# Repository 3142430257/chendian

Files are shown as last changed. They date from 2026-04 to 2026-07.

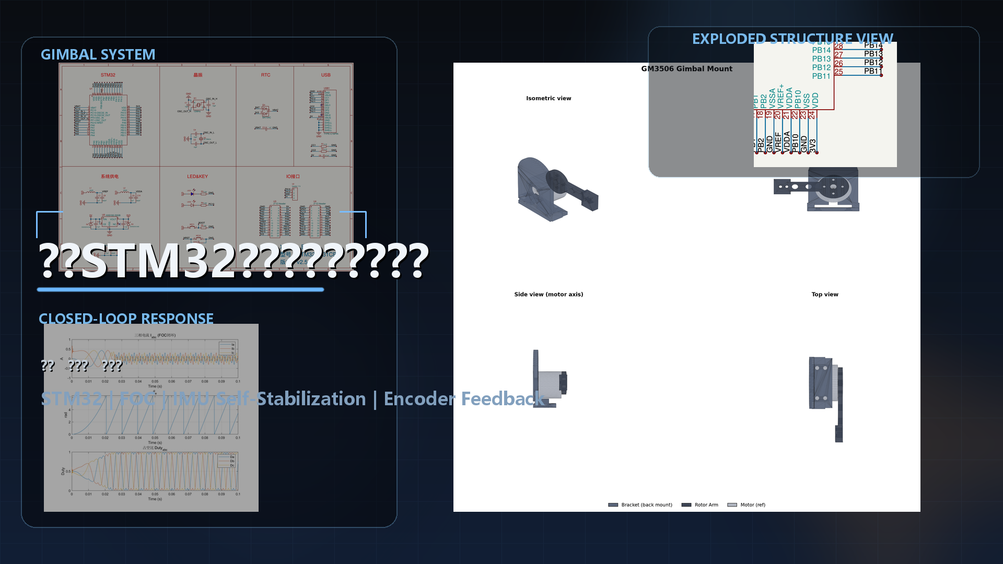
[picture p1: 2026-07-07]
docs/media/video_intro_cover_gimbal_stm32.png

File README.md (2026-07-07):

# STM32G431 FOC 单轴云台自稳系统

基于 **STM32G431CBT6 + GM3506 无刷云台电机** 的单轴 FOC 姿态自稳系统。项目覆盖下位机固件、Qt 图形上位机、Simulink 电流环模型、机械结构和竞赛文档。

全国大学生嵌入式芯片与系统设计竞赛 2026 · 意法半导体赛道 · 选题四：工业 4.0 / 电机控制 / 机器人

## 功能概览

| 功能 | 命令序列 | 说明 |
|---|---|---|
| 电角度校准 | `a` | 旋转式 ALIGN，建立可靠 dq 坐标 |
| 闭环速度控制 | `a -> e -> S40 -> S-40 -> S0 -> d` | 支持正反转和停机 |
| 单轴云台自稳 | `a -> e -> H -> G` | 底座倾斜时，负载臂保持相对水平 |
| 遥测与诊断 | Qt 上位机连接串口 | 实时显示位置、Iq、IMU pitch 和状态 |

## 系统架构

```text
MPU6050 IMU
    |
    v
位置目标 -> ISR 级位置 PID -> IqRef -> Simulink 电流 PI -> SVPWM -> GM3506
              ^                                             |
              |                                             v
        AS5048A SPI 编码器 <----------------------------- 转子位置
```

- **电流环**：Simulink 生成 PI 控制器，20 kHz PWM/ADC 同步中断执行。
- **位置环**：ISR 级 PID，使用编码器角度反馈，支持非线性 KP 和积分补偿。
- **校准流程**：开环旋转采样 + 电角度修正 + Iq 脉冲方向验证。
- **自稳模式**：MPU6050 pitch 映射为位置目标，电机反向补偿底座倾斜。
- **通信接口**：USART3，115200 8N1，支持单字符/行命令和 `T,...` CSV 遥测。

## 硬件组成

| 模块 | 型号/说明 |
|---|---|
| MCU | STM32G431CBT6，Cortex-M4，170 MHz |
| 电机 | GM3506 无刷云台电机，11 极对 |
| 驱动板 | ATK-PD6010B |
| 编码器 | AS5048A，14 bit SPI 磁编码器 |
| IMU | MPU6050，I2C |
| 电源 | 12 V DC |
| 串口 | USART3，PB10 TX，PB11 RX，115200 8N1 |

## 仓库结构

```text
firmware/
  STM32G431CBT6_motor/       当前主固件工程，CMake 构建
    App/                     FOC 接口、状态机、编码器、IMU、遥测
    Core/                    CubeMX 生成的 HAL 外设代码
  cubemx_reference/          早期 CubeMX 参考工程

host/
  qt_host/                   PySide6 图形上位机

models/
  foc_controller.slx         Simulink 电流环模型
  foc_sim.slx                闭环仿真模型
  foc_params.m               电机和 PI 参数
  foc_controller_ert_rtw/    Simulink Coder 生成代码与报告

hardware/
  gimbal_mount/              3D 打印支架 STL 与渲染图
  schematics_and_package/    原理图、封装、器件资料
  controller_board/          主控/驱动板参考资料

docs/
  report/                    竞赛报告与技术文档
  media/                     README/报告用图片
  references/                外部参考资料
```

说明：本地调试脚本目录 `tools/` 不上传 GitHub，已在 `.gitignore` 中忽略。

## 编译与烧录

依赖：

- STM32CubeCLT，包含 `arm-none-eabi-gcc`、CMake/Ninja 和 STM32CubeProgrammer
- STM32G431CBT6 目标板，SWD 下载接口

编译：

```powershell
cd firmware\STM32G431CBT6_motor
cmake --preset Debug
cmake --build --preset Debug
```

使用 STM32CubeProgrammer CLI 烧录：

```powershell
& 'D:\STM32CubeCLT_1.21.0\STM32CubeProgrammer\bin\STM32_Programmer_CLI.exe' `
  -c port=SWD mode=UR reset=HWrst `
  -w 'build\Debug\STM32G431CBT6_motor.elf' `
  -v -rst
```

如果 CMake 在中文路径下异常，建议把仓库复制到纯英文路径后再编译。

## Qt 上位机

依赖：

- Python 3.10+
- PySide6
- pyqtgraph
- pyserial
- numpy

启动：

```powershell
cd host\qt_host
pip install -r requirements.txt
python main.py
```

连接方式：

- USB 转 TTL 接 MCU `USART3 @ 115200`
- MCU `PB10` 为 TX，接 USB 转 TTL RX
- MCU `PB11` 为 RX，接 USB 转 TTL TX
- GND 必须共地
- 上电后等待状态进入 `ST=READY`，再执行使能或自稳流程

## 串口命令

| 命令 | 功能 |
|---|---|
| `a` | 旋转式电角度校准，ALIGN |
| `e` | 进入 RUN 使能状态 |
| `d` | 停机 |
| `H` | 将当前位置设为 Home 零点 |
| `G` | 启动 IMU 自稳模式 |
| `S<dps>` | 速度模式，例如 `S40` 表示 40 deg/s |
| `I<A>` | 直接力矩注入，例如 `I0.15` |
| `O` | 开环旋转测试 |
| `X` | 停止开环测试 |
| `F<deg>` | 手动微调电角度偏移 |

典型流程：

```text
a -> e -> H -> G
```

## 关键参数

| 参数 | 值 | 说明 |
|---|---|---|
| 电流环频率 | 20 kHz | PWM/ADC 同步 ISR |
| 电流环带宽 | 200 Hz | Simulink PI |
| 位置环更新 | 约 1 kHz | 编码器反馈 |
| 遥测频率 | 100 Hz | UART CSV 帧 |
| ISR_KP_NEAR | 0.015 A/deg | 小误差位置增益 |
| ISR_KP_FAR | 0.030 A/deg | 大误差位置增益 |
| ISR_KD | 0.010 A/(deg/s) | 阻尼项 |
| ISR_KI | 0.0005 A/(deg*s) | 重力静差积分补偿 |
| 速度保护 | 400 deg/s | ISR 级切断力矩 |

## 开发说明

- 主固件入口：`firmware/STM32G431CBT6_motor/`
- Qt 上位机入口：`host/qt_host/main.py`
- 电流环模型：`models/foc_controller.slx`
- 竞赛报告草稿：`docs/report/竞赛作品报告_填报稿.md`
- 本地视频、压缩包和调试脚本不纳入 GitHub

## 许可证

MIT License

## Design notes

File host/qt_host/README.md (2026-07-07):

# FOC 云台 Qt 上位机

深色工业风桌面控制台，对接固件 **USART3 @ 115200** CSV 遥测与单字符/行命令协议。

## 功能

- 串口连接、实时解析 `T,...` 遥测与 `[CMD]` 回显
- 实时曲线：位置 / Iq / IMU Pitch（约 60 s 滚动窗口）
- 一键流程：**校准 (a)** → **使能 (e)** → **Home (H)** → **自稳 (G)**
- 速度滑块 `S<dps>`、直接力矩 `I<amps>`、急停 **d**（连发 3 次）
- 软件看门狗（阈值可在界面中关闭）

## 环境

- Python 3.10+
- Windows / Linux（需 Qt 平台插件）

```powershell
cd host\qt_host
pip install -r requirements.txt
python main.py
```

## 硬件

USB 转 TTL 接 MCU **USART3 @ 115200**。上电后先等 `ST=READY` 再点「使能」。

## 目录

```
host/qt_host/
  main.py                 # 启动
  foc_host/
    main_window.py        # UI
    serial_worker.py      # 串口线程
    telemetry_parser.py   # CSV 解析
    theme.py              # 样式
```

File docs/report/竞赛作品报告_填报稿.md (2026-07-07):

# 作品名称

**STM32G431 磁场定向控制单轴云台姿态自稳系统**

（不要出现任何涉及学校名称和指导老师等内容）

---

## 摘要（800字内）

本项目面向工业现场对轻载姿态保持与小功率伺服的需求，设计并实现了一套基于 STM32G431CBT6 的单轴云台磁场定向控制（FOC）自稳系统。系统以 GM3506 无刷云台电机为执行机构，配合 ATK-PD6010B 三相驱动、AS5048A 磁编码器与 MPU6050 惯性测量单元，在 12 V 直流供电下完成电角度校准、闭环速度/位置控制及 IMU 辅助水平自稳。

软件采用“模型设计 + 嵌入式部署”路线：电流环 PI 与 SVPWM 由 Simulink Embedded Coder 自动生成并在 20 kHz PWM-ADC 同步中断中执行；位置环与自稳逻辑在应用层以约 1 kHz 更新，采用分段比例增益、微分阻尼与积分项消除重力静差。系统具备 ALIGN 旋转式零位校准、串口命令调度、100 Hz 遥测及母线电压/ADC 饱和等软件保护，上位机通过 Python 脚本实现一键流程与看门狗。

经仿真与实物验证，电机可按指令正反转（如 ±40°/s、±100°/s），在底座倾斜时进入自稳模式可保持负载臂相对水平。本作品将电机控制、传感器融合与工程化工具链结合，具有结构清晰、参数可追溯、便于扩展多轴与视觉伺服等特点，适用于巡检云台、小型机器人关节及教学科研中的 FOC 实践平台。

**【插图建议】** 系统实物斜 45° 照片；README 中控制架构框图（`docs/media/foc_verified_final.png` 或 `docs/media/foc_closedloop.png`）。

---

# 第一部分  作品概述

## 功能与特性（400字内）

本系统实现单轴云台的 FOC 驱动与姿态自稳。主要功能包括：（1）**电角度校准（ALIGN）**：开环采样结合 π/2 修正与 Iq 脉冲方向校验，建立可靠 dq 坐标；（2）**运行模式**：使能 RUN 后支持速度指令（S\<dps\>）、力矩注入（I\<A\>）、开环换相测试（O/X）及零点设定（H）；（3）**IMU 自稳（G）**：将 MPU6050 俯仰角映射为位置目标，电机反向补偿使臂端保持水平；（4）**安全与诊断**：母线 8–26 V 监测、ADC 饱和检测、速度超限切断、串口遥测与 dq 统计。

硬件上 MCU 170 MHz Cortex-M4 驱动 20 kHz 电流环；编码器 14 bit SPI 绝对角；通信采用 UART 字符协议，PC 端可通过 Qt 上位机或串口终端演示全流程。

**【插图建议】** 功能演示命令表截图（README）；自稳前后对比照片。

## 应用领域（400字内）

**工业 4.0 与机器人**：单轴稳定平台可用于轻量传感器载体、管道/廊道巡检相机云台、协作机械臂末端调姿等，在载体晃动时维持视轴或工具姿态。**无人机与光电吊舱**：原理可扩展至多轴万向节，为航拍、搜救提供稳像基础。**新能源与装备测试**：FOC 平台可用于电机参数辨识、驱动算法对比及 HIL 前的快速原型。**教育与竞赛**：覆盖 CubeMX 外设、Simulink 代码生成、CMake 交叉编译与现场调试，契合嵌入式芯片与电机控制选题。

本方案强调低成本商用模块（GM3506、PD6010B、磁编）与开源工具链，便于实验室复现与二次开发。

**【插图建议】** 应用场景示意图（巡检/稳像示意，可手绘）。

## 主要技术特点（400字内）

（1）**分层控制架构**：电流环 20 kHz（Simulink 生成 PI + SVPWM），位置/自稳环 1 kHz（非线性 KP、KD、KI），职责清晰、易于调参。（2）**模型驱动开发**：`models/foc_controller.slx` 与 `models/foc_params.m` 统一带宽（200 Hz）与限幅，生成代码与 `foc_interface.c` ISR 无缝对接。（3）**高精度角度链**：AS5048A SPI 绝对编码 + 旋转校准，消除安装误差；IMU 提供重力参考实现外环补偿。（4）**工程化状态机**：INIT→CALIBRATE→READY→RUN/FAULT，含零偏采集、对齐验证与故障复位策略。（5）**可观测性**：100 Hz 遥测、Simulink 闭环仿真（`models/foc_sim.slx`）及 Python 监控，缩短“仿真—下位机”迭代周期。（6）**机械适配**：`hardware/gimbal_mount/` 提供 3D 打印支架 STL，便于快速搭建单轴演示台。

## 主要性能指标（200字内，建议用表格）

| 指标项 | 参数 |
|---|---|
| 主控 MCU | STM32G431CBT6，170 MHz |
| 电机 | GM3506，11 极对 |
| 电流环执行频率 | 20 kHz |
| 电流环设计带宽 | 200 Hz（Simulink PI） |
| 编码器 | AS5048A，14 bit SPI |
| IMU | MPU6050，I2C |
| 供电 | 12 V DC，母线保护 8–26 V |
| 速度模式 | 指令示例 ±40°/s、±100°/s |
| 速度保护 | 400°/s（ISR 切断力矩） |
| 位置环输出限幅 | 约 45°/s（应用层） |
| 遥测 | UART 100 Hz |

## 主要创新点（200字以内，逐点给出）

1. **Simulink 电流环 + ISR 位置自稳**：内环模型自动生成，外环针对重力静差定制分段 KP 与积分，兼顾响应与平稳。  
2. **旋转式 ALIGN 流程**：结合开环角与编码器互校验，降低磁编安装误差对 FOC 的影响。  
3. **IMU—编码器双反馈自稳**：俯仰角作位置目标，编码器闭环执行，底座倾斜时仍保持水平。  
4. **上位机演示与看门狗**：Qt 上位机一键串联校准、使能、自稳，便于竞赛现场复现。
5. **完整开源链路**：CubeMX + CMake + Simulink ERT + 仿真图，参数与代码同源可追溯。

## 设计流程（200字内）

需求分析（单轴稳像、FOC）→ 电机与驱动选型 → Simulink 电流环建模与 `models/foc_sim.slx` 闭环验证 → CubeMX 配置 TIM1/ADC/SPI/I2C/UART → 集成 ERT 代码与 `app_control` 状态机 → 编码器/IMU 驱动与 ALIGN → 位置与自稳联调 → 3D 打印机械件装配 → 串口协议与 Python 工具 → 实物指标测试与文档整理。

**【插图建议】** 设计流程框图（6–8 步）。

---

# 第二部分  系统组成及功能说明

## 整体介绍

系统由**功率与驱动**、**传感**、**控制计算**、**人机交互**四部分组成。12 V 经驱动板 ATK-PD6010B 逆变驱动 GM3506；STM32G431 通过 TIM1 输出 SVPWM，ADC 同步采样三相电流与母线/温度；AS5048A 经 SPI 提供转子位置，MPU6050 经 I2C 提供姿态；UART 连接 PC 下发 a/e/H/G/S 等命令并上传遥测。

**数据流**：IMU pitch / 用户指令 → 位置目标 → ISR 级 PID → Iq 参考 → Simulink 电流 PI → SVPWM → 电机；编码器角度反馈至位置环与 FOC 电角度。请在正文插入系统框图（可参考 README 架构图并标注各模块与信号线）。

## 硬件系统介绍

### 2.2.1 硬件整体介绍

核心为 STM32G431CBT6 最小系统 + ATK-PD6010B 三相桥 + GM3506 电机；传感包括 AS5048A（轴端磁编）与 MPU6050（IMU 模块）；电源 12 V，逻辑 3.3 V。MCU 负责 PWM、电流采样、通信与实时算法；驱动板完成功率放大与保护。整体为桌面级单轴演示平台，便于示波器测电流与串口观察状态。

**【插图】** 硬件实物全景、模块连接照片。

### 2.2.2 机械设计介绍

采用 `hardware/gimbal_mount/` 中 3D 打印支架固定电机、IMU 与负载臂，保证 IMU 与旋转轴关系稳定、负载质心接近轴心以减小重力矩。设计从**总成布局**（底座—电机—臂—传感器）到**紧固与走线**逐级说明，并给出 CAD/STL 渲染或实物照片。若使用手绘草图，需标注轴系与 IMU 安装方向。

### 2.2.3 电路各模块介绍

**总体**：MCU 板—驱动板—电机三相线；SPI 接编码器，I2C 接 IMU，UART 接 USB 转串口；ADC 采电流与母线。**分区说明**：（1）功率与驱动 ATK-PD6010B；（2）MCU 最小系统与时钟；（3）电流采样与运放通道（标注 IU/IV/IW、VBUS）；（4）编码器 SPI（CLK/MISO/MOSI/CS）；（5）IMU I2C（SCL/SDA）。请插入 `hardware/schematics_and_package/` 中 SCH、PCB 截图，并用箭头标出关键信号走向。

## 软件系统介绍

### 2.3.1 软件整体介绍

软件分**下位机固件**（`firmware/STM32G431CBT6_motor/`）与**图形上位机**（`host/qt_host/`）及**离线仿真**（MATLAB/Simulink）。固件基于 HAL + CMake 构建；应用层 `app_control.c` 状态机，`foc_interface.c` 负责 ISR 内测量、电流环 step 与保护；Simulink 生成 `foc_controller.c`。PC 端通过串口发送单字符命令并可选绘制遥测曲线。

**【插图】** Simulink 模型截图、串口工具运行界面、`docs/media/foc_closedloop.png` 仿真结果。

### 2.3.2 软件各模块介绍

| 模块 | 文件 | 功能要点 |
|---|---|---|
| 状态机与模式 | `app_control.c` | INIT/CALIBRATE/READY/RUN/FAULT；速度/位置/自稳；ALIGN |
| FOC 接口 | `foc_interface.c` | ADC→物理量；20 kHz 调用 foc_controller_step；开环调试 |
| 电流环 | `foc_controller.c`（ERT） | Id/Iq PI，SVPWM 占空比输出 |
| 编码器 | `encoder_spi.c` | AS5048A 读角、速度估计 |
| IMU | `mpu6050.c` | 俯仰角、自稳目标 |
| 遥测 | `telemetry.c` | 100 Hz 帧上传 |
| 上位机 | `host/qt_host/` | 命令序列、遥测曲线与 watchdog |

**流程说明（文字级）**：`main` 初始化外设 → 校准零偏 → 主循环 `app_control_update` 读 IMU/故障 → PWM ISR 内 `foc_interface_isr` 更新电流环并读编码器参与位置 PID。关键变量：`iq_ref`、`theta_e`、位置误差 `deg`、IMU pitch。可补充各函数流程图（draw.io/Visio）。

---

# 第三部分  完成情况及性能参数

## 整体介绍

请插入**系统实物正面**与**斜 45° 全局**照片各一张，展示电机、驱动、主控、负载臂与线束整理效果。

## 工程成果

### 3.2.1 机械成果

3D 打印支架装配完成，电机轴与负载臂同轴度满足演示要求；自稳测试时底座可手动倾斜约 45°，臂端仍趋向水平（请附照片/短视频截图）。

### 3.2.2 电路成果

驱动板与 MCU 联调通过，三相 PWM 与电流采样正常；SPI 编码器、I2C IMU 通信稳定。附 PCB 焊接面/正面及上电指示灯照片。

### 3.2.3 软件成果

附串口终端或 Qt 上位机执行 `a→e→H→G` 的截图；Simulink 仿真波形（`docs/media/foc_verified_final.png`）；可选 CMake 编译成功与烧录日志。

## 特性成果（量化指标）

| 验证项 | 方法 | 结果 |
|---|---|---|
| 速度跟踪 | 命令 S40/S-40/S100/S0 | 方向与转速可跟随指令 |
| 自稳 | 底座倾斜 + G 模式 | 负载臂保持水平趋势 |
| 电流环 | 示波器/遥测 Iq | 20 kHz 稳定运行 |
| 保护 | 低母线/ADC 异常 | 进入 FAULT 并停机 |

**【插图】** 示波器电流波形、自稳现场照片、仿真对比图。

---

# 第四部分  总结

## 可扩展之处（300字内）

可扩展为**双轴/三轴云台**，增加第二路 FOC 与 yaw 轴编码器；引入 **CAN/EtherCAT** 替代 UART 便于工业组网；在位置环外增加 **视觉伺服**（OpenMV/树莓派）实现目标跟踪；对 `models/foc_params.m` 做 **在线参数辨识** 适配不同电机；增加 **FreRTOS** 划分通信与日志任务；机械上采用 CNC 支架提高刚度；安全方面完善编码器去抖、过温与硬件急停，满足更长时运行。

## 心得体会（1000字内）

本作品从选题、仿真到下位机联调，完整走通了 STM32G4 电机控制链路。初期在电流采样符号、相序与 ADC 通道映射上花费较多时间，通过 `FOC_DBG_FIXED_VECTOR` 等分级调试手段逐相验证，体会到“先开环、再闭环、最后上负载”的必要性。Simulink 生成代码显著降低手写 PI 与限幅错误，但 ISR 时序与全局变量接口仍需严格约定，否则会出现积分饱和或抖动。

ALIGN 与磁编安装高度相关，旋转校准 + 手动 F 微调命令提高了现场适应性。自稳模式将 IMU 与位置环结合，重力矩由积分项消化，分段 KP 则在远近误差下平衡快速性与平稳性。上位机脚本化演示极大方便竞赛展示，也暴露协议需防误触与看门狗的必要性。

机械结构虽为 3D 打印，质心与轴系对齐对自稳效果影响明显，后续应在 CAD 阶段做简单动力学估算。整体而言，项目整合了意法半导体 MCU、FOC 算法、传感器融合与工程工具链，为工业 4.0 电机控制场景提供了可复现的原型平台；后续将在多轴协调、参数自整定与更长可靠性测试上继续完善。

---

# 第五部分  参考文献（20篇以内）

[1] TI. Field Oriented Control of 3-Phase AC Motors. Literature Number: SPRU723, 2013.  
[2] ST Microelectronics. STM32G431xx Datasheet and Reference Manual, 2024.  
[3] ST Microelectronics. AN1076: Sensorless Field Oriented Control of PMSM Motors.  
[4] ST Microelectronics. AN4680: Field-oriented control of PMSM driven by sensorless algorithm.  
[5] MathWorks. Embedded Coder User's Guide, R2024b.  
[6] ams OSRAM. AS5048A Magnetic Position Sensor Datasheet.  
[7] InvenSense. MPU-6000/6050 Product Specification.  
[8] Bose B K. Modern Power Electronics and AC Drives. Prentice Hall, 2002.  
[9] Mohan N. Power Electronics: A First Course. Wiley, 2012.  
[10] 王成元, 夏加宽, 杨俊友. 电机现代控制技术. 机械工业出版社.  
[11] 陈伯时. 电力拖动自动控制系统——运动控制系统. 机械工业出版社.  
[12] 全国大学生嵌入式芯片与系统设计竞赛 2026 竞赛指南（意法半导体赛道）.  
[13] ARM Ltd. CMSIS-DSP Software Library Documentation.  
[14] STM32CubeG4 User Manual: TIM PWM Generation and ADC Injection.  
[15] Atkinson K E. Numerical Analysis for SVPWM Modulation Principles (textbooks).  
[16] Python Software Foundation. pyserial Documentation.  
[17] GitHub. STM32 HAL Driver Overview and Best Practices.  
[18] J. Wang et al. Permanent Magnet Synchronous Machine Model for Field-Oriented Control. IEEE.  
[19] ISO/IEC/IEEE 12207:2017 Systems and software engineering — Software life cycle processes.  
[20] MIT License Open Source Software Licensing (project README).

---

**说明**：请将文中【插图建议】替换为实际照片/截图后，复制到原 Word 模板对应章节。勿在正式稿中保留学校名、指导教师姓名。

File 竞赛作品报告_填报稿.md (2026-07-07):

# 作品名称

**STM32G431 磁场定向控制单轴云台姿态自稳系统**

（不要出现任何涉及学校名称和指导老师等内容）

---

## 摘要（800字内）

本项目面向工业现场对轻载姿态保持与小功率伺服的需求，设计并实现了一套基于 STM32G431CBT6 的单轴云台磁场定向控制（FOC）自稳系统。系统以 GM3506 无刷云台电机为执行机构，配合 ATK-PD6010B 三相驱动、AS5048A 磁编码器与 MPU6050 惯性测量单元，在 12 V 直流供电下完成电角度校准、闭环速度/位置控制及 IMU 辅助水平自稳。

软件采用“模型设计 + 嵌入式部署”路线：电流环 PI 与 SVPWM 由 Simulink Embedded Coder 自动生成并在 20 kHz PWM-ADC 同步中断中执行；位置环与自稳逻辑在应用层以约 1 kHz 更新，采用分段比例增益、微分阻尼与积分项消除重力静差。系统具备 ALIGN 旋转式零位校准、串口命令调度、100 Hz 遥测及母线电压/ADC 饱和等软件保护，上位机通过 Python 脚本实现一键流程与看门狗。

经仿真与实物验证，电机可按指令正反转（如 ±40°/s、±100°/s），在底座倾斜时进入自稳模式可保持负载臂相对水平。本作品将电机控制、传感器融合与工程化工具链结合，具有结构清晰、参数可追溯、便于扩展多轴与视觉伺服等特点，适用于巡检云台、小型机器人关节及教学科研中的 FOC 实践平台。

**【插图建议】** 系统实物斜 45° 照片；README 中控制架构框图（`foc_verified_final.png` 或 `foc_closedloop.png`）。

---

# 第一部分  作品概述

## 功能与特性（400字内）

本系统实现单轴云台的 FOC 驱动与姿态自稳。主要功能包括：（1）**电角度校准（ALIGN）**：开环采样结合 π/2 修正与 Iq 脉冲方向校验，建立可靠 dq 坐标；（2）**运行模式**：使能 RUN 后支持速度指令（S\<dps\>）、力矩注入（I\<A\>）、开环换相测试（O/X）及零点设定（H）；（3）**IMU 自稳（G）**：将 MPU6050 俯仰角映射为位置目标，电机反向补偿使臂端保持水平；（4）**安全与诊断**：母线 8–26 V 监测、ADC 饱和检测、速度超限切断、串口遥测与 dq 统计。

硬件上 MCU 170 MHz Cortex-M4 驱动 20 kHz 电流环；编码器 14 bit SPI 绝对角；通信采用 UART 字符协议，PC 端 `foc_ctl.py` 可脚本化演示全流程。

**【插图建议】** 功能演示命令表截图（README）；自稳前后对比照片。

## 应用领域（400字内）

**工业 4.0 与机器人**：单轴稳定平台可用于轻量传感器载体、管道/廊道巡检相机云台、协作机械臂末端调姿等，在载体晃动时维持视轴或工具姿态。**无人机与光电吊舱**：原理可扩展至多轴万向节，为航拍、搜救提供稳像基础。**新能源与装备测试**：FOC 平台可用于电机参数辨识、驱动算法对比及 HIL 前的快速原型。**教育与竞赛**：覆盖 CubeMX 外设、Simulink 代码生成、CMake 交叉编译与现场调试，契合嵌入式芯片与电机控制选题。

本方案强调低成本商用模块（GM3506、PD6010B、磁编）与开源工具链，便于实验室复现与二次开发。

**【插图建议】** 应用场景示意图（巡检/稳像示意，可手绘）。

## 主要技术特点（400字内）

（1）**分层控制架构**：电流环 20 kHz（Simulink 生成 PI + SVPWM），位置/自稳环 1 kHz（非线性 KP、KD、KI），职责清晰、易于调参。（2）**模型驱动开发**：`foc_controller.slx` 与 `foc_params.m` 统一带宽（200 Hz）与限幅，生成代码与 `foc_interface.c` ISR 无缝对接。（3）**高精度角度链**：AS5048A SPI 绝对编码 + 旋转校准，消除安装误差；IMU 提供重力参考实现外环补偿。（4）**工程化状态机**：INIT→CALIBRATE→READY→RUN/FAULT，含零偏采集、对齐验证与故障复位策略。（5）**可观测性**：100 Hz 遥测、Simulink 闭环仿真（`foc_sim.slx`）及 Python 监控，缩短“仿真—下位机”迭代周期。（6）**机械适配**：`gimbal_mount/` 提供 3D 打印支架 STL，便于快速搭建单轴演示台。

## 主要性能指标（200字内，建议用表格）

| 指标项 | 参数 |
|---|---|
| 主控 MCU | STM32G431CBT6，170 MHz |
| 电机 | GM3506，11 极对 |
| 电流环执行频率 | 20 kHz |
| 电流环设计带宽 | 200 Hz（Simulink PI） |
| 编码器 | AS5048A，14 bit SPI |
| IMU | MPU6050，I2C |
| 供电 | 12 V DC，母线保护 8–26 V |
| 速度模式 | 指令示例 ±40°/s、±100°/s |
| 速度保护 | 400°/s（ISR 切断力矩） |
| 位置环输出限幅 | 约 45°/s（应用层） |
| 遥测 | UART 100 Hz |

## 主要创新点（200字以内，逐点给出）

1. **Simulink 电流环 + ISR 位置自稳**：内环模型自动生成，外环针对重力静差定制分段 KP 与积分，兼顾响应与平稳。  
2. **旋转式 ALIGN 流程**：结合开环角与编码器互校验，降低磁编安装误差对 FOC 的影响。  
3. **IMU—编码器双反馈自稳**：俯仰角作位置目标，编码器闭环执行，底座倾斜时仍保持水平。  
4. **脚本化演示与看门狗**：`foc_ctl.py` 一键串联校准、使能、自稳，便于竞赛现场复现。  
5. **完整开源链路**：CubeMX + CMake + Simulink ERT + 仿真图，参数与代码同源可追溯。

## 设计流程（200字内）

需求分析（单轴稳像、FOC）→ 电机与驱动选型 → Simulink 电流环建模与 `foc_sim.slx` 闭环验证 → CubeMX 配置 TIM1/ADC/SPI/I2C/UART → 集成 ERT 代码与 `app_control` 状态机 → 编码器/IMU 驱动与 ALIGN → 位置与自稳联调 → 3D 打印机械件装配 → 串口协议与 Python 工具 → 实物指标测试与文档整理。

**【插图建议】** 设计流程框图（6–8 步）。

---

# 第二部分  系统组成及功能说明

## 整体介绍

系统由**功率与驱动**、**传感**、**控制计算**、**人机交互**四部分组成。12 V 经驱动板 ATK-PD6010B 逆变驱动 GM3506；STM32G431 通过 TIM1 输出 SVPWM，ADC 同步采样三相电流与母线/温度；AS5048A 经 SPI 提供转子位置，MPU6050 经 I2C 提供姿态；UART 连接 PC 下发 a/e/H/G/S 等命令并上传遥测。

**数据流**：IMU pitch / 用户指令 → 位置目标 → ISR 级 PID → Iq 参考 → Simulink 电流 PI → SVPWM → 电机；编码器角度反馈至位置环与 FOC 电角度。请在正文插入系统框图（可参考 README 架构图并标注各模块与信号线）。

## 硬件系统介绍

### 2.2.1 硬件整体介绍

核心为 STM32G431CBT6 最小系统 + ATK-PD6010B 三相桥 + GM3506 电机；传感包括 AS5048A（轴端磁编）与 MPU6050（IMU 模块）；电源 12 V，逻辑 3.3 V。MCU 负责 PWM、电流采样、通信与实时算法；驱动板完成功率放大与保护。整体为桌面级单轴演示平台，便于示波器测电流与串口观察状态。

**【插图】** 硬件实物全景、模块连接照片。

### 2.2.2 机械设计介绍

采用 `gimbal_mount/` 中 3D 打印支架固定电机、IMU 与负载臂，保证 IMU 与旋转轴关系稳定、负载质心接近轴心以减小重力矩。设计从**总成布局**（底座—电机—臂—传感器）到**紧固与走线**逐级说明，并给出 CAD/STL 渲染或实物照片。若使用手绘草图，需标注轴系与 IMU 安装方向。

### 2.2.3 电路各模块介绍

**总体**：MCU 板—驱动板—电机三相线；SPI 接编码器，I2C 接 IMU，UART 接 USB 转串口；ADC 采电流与母线。**分区说明**：（1）功率与驱动 ATK-PD6010B；（2）MCU 最小系统与时钟；（3）电流采样与运放通道（标注 IU/IV/IW、VBUS）；（4）编码器 SPI（CLK/MISO/MOSI/CS）；（5）IMU I2C（SCL/SDA）。请插入 `原理图&封装/` 中 SCH、PCB 截图，并用箭头标出关键信号走向。

## 软件系统介绍

### 2.3.1 软件整体介绍

软件分**下位机固件**（`STM32G431CBT6_Motor/`）与**上位机工具**（`tmp/foc_ctl.py`、`foc_monitor.py`）及**离线仿真**（MATLAB/Simulink）。固件基于 HAL + CMake 构建；应用层 `app_control.c` 状态机，`foc_interface.c` 负责 ISR 内测量、电流环 step 与保护；Simulink 生成 `foc_controller.c`。PC 端通过串口发送单字符命令并可选绘制遥测曲线。

**【插图】** Simulink 模型截图、串口工具运行界面、`foc_closedloop.png` 仿真结果。

### 2.3.2 软件各模块介绍

| 模块 | 文件 | 功能要点 |
|---|---|---|
| 状态机与模式 | `app_control.c` | INIT/CALIBRATE/READY/RUN/FAULT；速度/位置/自稳；ALIGN |
| FOC 接口 | `foc_interface.c` | ADC→物理量；20 kHz 调用 foc_controller_step；开环调试 |
| 电流环 | `foc_controller.c`（ERT） | Id/Iq PI，SVPWM 占空比输出 |
| 编码器 | `encoder_spi.c` | AS5048A 读角、速度估计 |
| IMU | `mpu6050.c` | 俯仰角、自稳目标 |
| 遥测 | `telemetry.c` | 100 Hz 帧上传 |
| 上位机 | `foc_ctl.py` | 命令序列与 watchdog |

**流程说明（文字级）**：`main` 初始化外设 → 校准零偏 → 主循环 `app_control_update` 读 IMU/故障 → PWM ISR 内 `foc_interface_isr` 更新电流环并读编码器参与位置 PID。关键变量：`iq_ref`、`theta_e`、位置误差 `deg`、IMU pitch。可补充各函数流程图（draw.io/Visio）。

---

# 第三部分  完成情况及性能参数

## 整体介绍

请插入**系统实物正面**与**斜 45° 全局**照片各一张，展示电机、驱动、主控、负载臂与线束整理效果。

## 工程成果

### 3.2.1 机械成果

3D 打印支架装配完成，电机轴与负载臂同轴度满足演示要求；自稳测试时底座可手动倾斜约 45°，臂端仍趋向水平（请附照片/短视频截图）。

### 3.2.2 电路成果

驱动板与 MCU 联调通过，三相 PWM 与电流采样正常；SPI 编码器、I2C IMU 通信稳定。附 PCB 焊接面/正面及上电指示灯照片。

### 3.2.3 软件成果

附串口终端执行 `a→e→H→G` 或 `foc_ctl.py run "..."` 的截图；Simulink 仿真波形（`foc_verified_final.png`）；可选 CMake 编译成功与烧录日志。

## 特性成果（量化指标）

| 验证项 | 方法 | 结果 |
|---|---|---|
| 速度跟踪 | 命令 S40/S-40/S100/S0 | 方向与转速可跟随指令 |
| 自稳 | 底座倾斜 + G 模式 | 负载臂保持水平趋势 |
| 电流环 | 示波器/遥测 Iq | 20 kHz 稳定运行 |
| 保护 | 低母线/ADC 异常 | 进入 FAULT 并停机 |

**【插图】** 示波器电流波形、自稳现场照片、仿真对比图。

---

# 第四部分  总结

## 可扩展之处（300字内）

可扩展为**双轴/三轴云台**，增加第二路 FOC 与 yaw 轴编码器；引入 **CAN/EtherCAT** 替代 UART 便于工业组网；在位置环外增加 **视觉伺服**（OpenMV/树莓派）实现目标跟踪；对 `foc_params.m` 做 **在线参数辨识** 适配不同电机；增加 **FreRTOS** 划分通信与日志任务；机械上采用 CNC 支架提高刚度；安全方面完善编码器去抖、过温与硬件急停，满足更长时运行。

## 心得体会（1000字内）

本作品从选题、仿真到下位机联调，完整走通了 STM32G4 电机控制链路。初期在电流采样符号、相序与 ADC 通道映射上花费较多时间，通过 `FOC_DBG_FIXED_VECTOR` 等分级调试手段逐相验证，体会到“先开环、再闭环、最后上负载”的必要性。Simulink 生成代码显著降低手写 PI 与限幅错误，但 ISR 时序与全局变量接口仍需严格约定，否则会出现积分饱和或抖动。

ALIGN 与磁编安装高度相关，旋转校准 + 手动 F 微调命令提高了现场适应性。自稳模式将 IMU 与位置环结合，重力矩由积分项消化，分段 KP 则在远近误差下平衡快速性与平稳性。上位机脚本化演示极大方便竞赛展示，也暴露协议需防误触与看门狗的必要性。

机械结构虽为 3D 打印，质心与轴系对齐对自稳效果影响明显，后续应在 CAD 阶段做简单动力学估算。整体而言，项目整合了意法半导体 MCU、FOC 算法、传感器融合与工程工具链，为工业 4.0 电机控制场景提供了可复现的原型平台；后续将在多轴协调、参数自整定与更长可靠性测试上继续完善。

---

# 第五部分  参考文献（20篇以内）

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

---

**说明**：请将文中【插图建议】替换为实际照片/截图后，复制到原 Word 模板对应章节。勿在正式稿中保留学校名、指导教师姓名。

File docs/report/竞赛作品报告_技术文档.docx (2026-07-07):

## 基于STM32G431的高性能无刷电机FOC系统与电流环高带宽协同优化及

## 摘要

本项目面向工业现场对轻载姿态保持与小功率伺服的需求，设计并实现了一套基于 STM32G431CBT6 的单轴云台磁场定向控制（FOC）自稳系统。系统以 GM3506 无刷云台电机为执行机构，配合 ATK-PD6010B 三相驱动、AS5048A 磁编码器与 MPU6050 惯性测量单元，在 12 V 直流供电下完成电角度校准、闭环速度/位置控制及 IMU 辅助水平自稳。

软件采用“模型设计 + 嵌入式部署 + 图形化调试”路线：电流环 PI 与 SVPWM 由 Simulink Embedded Coder 自动生成并在 20 kHz PWM-ADC 同步中断中执行；位置环与自稳逻辑在应用层以约 1 kHz 更新，采用分段比例增益、微分阻尼与积分项消除重力静差。系统具备 ALIGN 旋转式零位校准、串口命令调度、100 Hz 遥测及母线电压/ADC 饱和等软件保护；PC 端除脚本化 foc_ctl.py 外，新增基于 PySide6 的 Qt 图形上位机，实现串口连接、实时曲线、标准流程按钮、速度/Iq 调节与软件看门狗，便于现场演示和联调。

经仿真与实物验证，电机可按指令正反转（如 ±40°/s、±100°/s），在底座倾斜时进入自稳模式可保持负载臂相对水平。本作品将电机控制、传感器融合与工程化工具链结合，具有结构清晰、参数可追溯、便于扩展多轴与视觉伺服等特点，适用于巡检云台、教学科研中的 FOC 实践平台。

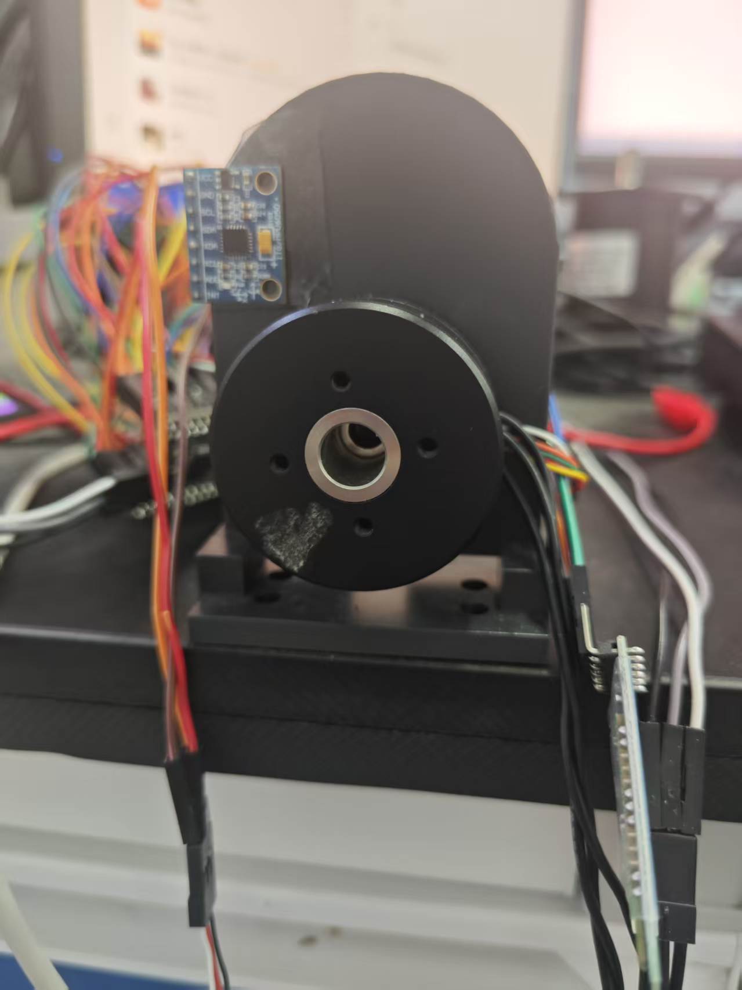
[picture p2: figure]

# 第一部分 作品概述

1.1功能与特性：本系统实现单轴云台的 FOC 驱动与姿态自稳。主要功能包括：（1）电角度校准（ALIGN）：开环采样结合 π/2 修正与 Iq 脉冲方向校验，建立可靠 dq 坐标；（2）运行模式：使能 RUN 后支持速度指令（S<dps>）、力矩注入（I<A>）、开环换相测试（O/X）及零点设定（H）；（3）IMU 自稳（G）：将 MPU6050 俯仰角映射为位置目标，电机反向补偿使臂端保持水平；（4）安全与诊断：母线 8–26 V 监测、ADC 饱和检测、速度超限切断、串口遥测与 dq 统计。

硬件上 MCU 170 MHz Cortex-M4 驱动 20 kHz 电流环；编码器 14 bit SPI 绝对角；通信采用 UART 字符协议，PC 端既可用 foc_ctl.py 脚本化演示全流程，也可通过 qt_host 图形上位机完成端口选择、遥测可视化、标准自稳流程控制、速度/力矩调试和急停保护。

1.2应用领域：工业 4.0 与机器人：单轴稳定平台可用于轻量传感器载体、管道/廊道巡检相机云台、协作机械臂末端调姿等，在载体晃动时维持视轴或工具姿态。无人机与光电吊舱：原理可扩展至多轴万向节，为航拍、搜救提供稳像基础。新能源与装备测试：FOC 平台可用于电机参数辨识、驱动算法对比及 HIL 前的快速原型。教育与竞赛：覆盖 CubeMX 外设、Simulink 代码生成、CMake 交叉编译与现场调试，契合嵌入式芯片与电机控制选题。

本方案强调低成本商用模块（GM3506、PD6010B、磁编）与开源工具链，便于实验室复现与二次开发。

1.3主要技术特点:（1）分层控制架构：电流环 20 kHz（Simulink 生成 PI + SVPWM），位置/自稳环 1 kHz（非线性 KP、KD、KI），职责清晰、易于调参。（2）模型驱动开发：foc_controller.slx 与 foc_params.m 统一带宽（200 Hz）与限幅，生成代码与 foc_interface.c ISR 无缝对接。（3）高精度角度链：AS5048A SPI 绝对编码 + 旋转校准，消除安装误差；IMU 提供重力参考实现外环补偿。（4）工程化状态机：INIT→CALIBRATE→READY→RUN/FAULT，含零偏采集、对齐验证与故障复位策略。（5）可观测性：100 Hz 遥测、Simulink 闭环仿真（foc_sim.slx）及 Python 监控，缩短"仿真—下位机"迭代周期。（6）机械适配：gimbal_mount/ 提供 3D 打印支架 STL，便于快速搭建单轴演示台。

1.4主要性能指标:

指标项 | 参数
主控 MCU | STM32G431CBT6，170 MHz
电机 | GM3506，11 极对
电流环执行频率 | 20 kHz
电流环设计带宽 | 200 Hz（Simulink PI）
编码器 | AS5048A，14 bit SPI
IMU | MPU6050，I2C
供电 | 12 V DC，母线保护 8–26 V
速度模式 | 指令示例 ±40°/s、±100°/s
速度保护 | 400°/s（ISR 切断力矩）
位置环输出限幅 | 约 45°/s（应用层）
遥测 | UART 100 Hz
上位机交互 | PySide6 图形界面；USART3 115200；实时位置/Iq/IMU 曲线；流程按钮与软件看门狗

1.5主要创新点:

1. Simulink 电流环 + ISR 位置自稳：内环模型自动生成，外环针对重力静差定制分段 KP 与积分，兼顾响应与平稳。

2. 旋转式 ALIGN 流程：结合开环角与编码器互校验，降低磁编安装误差对 FOC 的影响。 3. IMU—编码器双反馈自稳：俯仰角作位置目标，编码器闭环执行，底座倾斜时仍保持水平。 4. 图形化上位机与脚本化调试并行：foc_ctl.py 支持一键串联校准、使能、自稳，qt_host 基于 PySide6 提供实时位置/Iq/IMU 曲线、流程按钮、速度滑块、力矩注入、三连发急停和软件看门狗，提升比赛现场演示与故障定位效率。 5. 完整开源链路：CubeMX + CMake + Simulink ERT + Qt/Python 上位机 + 仿真图，参数与代码同源可追溯。

1.6设计流程: 需求分析（单轴稳像、FOC）→ 电机与驱动选型 → Simulink 电流环建模与 foc_sim.slx 闭环验证 → CubeMX 配置 TIM1/ADC/SPI/I2C/UART → 集成 ERT 代码与 app_control 状态机 → 编码器/IMU 驱动与 ALIGN → 位置与自稳联调 → 3D 打印机械件装配 → 串口协议、Python 脚本与 Qt 图形上位机开发 → 实物指标测试、遥测曲线核查与文档整理。

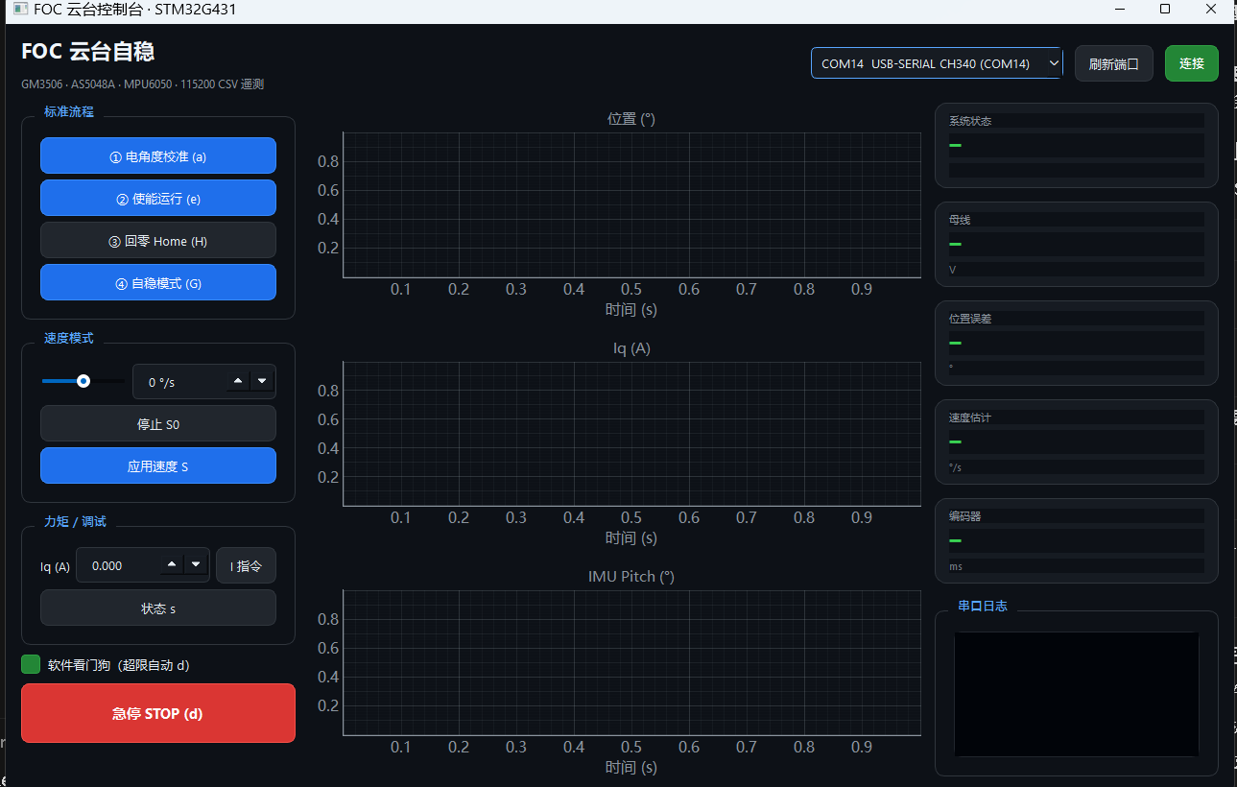
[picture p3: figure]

## 第二部分 系统组成及功能说明

2.1整体介绍

系统由功率与驱动、传感、控制计算、人机交互四部分组成。12 V 经驱动板 ATK-PD6010B 逆变驱动 GM3506；STM32G431 通过 TIM1 输出 SVPWM，ADC 同步采样三相电流与母线/温度；AS5048A 经 SPI 提供转子位置，MPU6050 经 I2C 提供姿态；UART 连接 PC 下发 a/e/H/G/S/I/d 等命令并上传 T,... CSV 遥测。人机交互层包含命令行脚本与 Qt 图形上位机：脚本适合自动化复现实验，Qt 上位机适合比赛现场连接、曲线观察、流程控制和急停保护。数据流：IMU pitch / 用户指令 → 位置目标 → ISR 级位置控制 → IqRef → FOC 电流环 → SVPWM → 三相驱动 → 编码器/电流/IMU 反馈闭环。

2.2硬件系统介绍

2.2.1 硬件整体介绍核心为 STM32G431CBT6 最小系统 + ATK-PD6010B 三相桥 + GM3506 电机；传感包括 AS5048A（轴端磁编）与 MPU6050（IMU 模块）；电源 12 V，逻辑 3.3 V。MCU 负责 PWM、电流采样、通信与实时算法；驱动板完成功率放大与保护。整体为桌面级单轴演示平台，便于示波器测电流与串口观察状态。

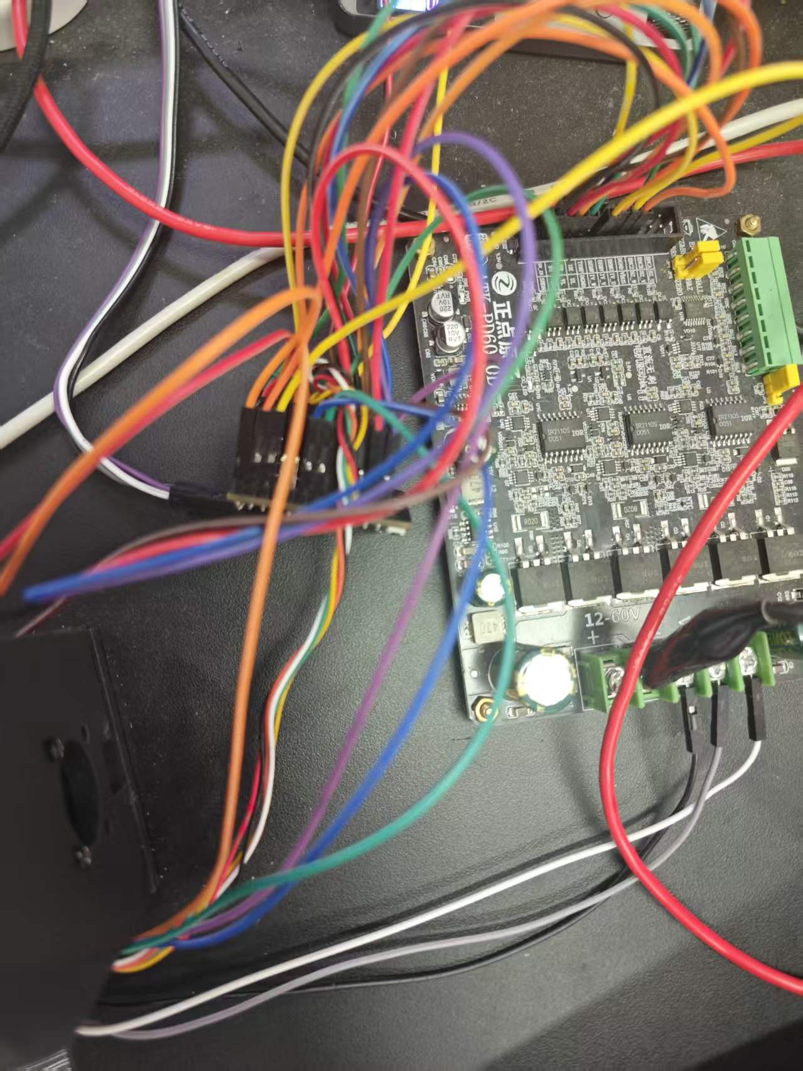
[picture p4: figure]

2.2.2 机械设计介绍：采用 gimbal_mount/ 中 3D 打印支架固定电机、IMU 与负载臂，保证 IMU 与旋转轴关系稳定、负载质心接近轴心以减小重力矩。

2.2.3 电路各模块介绍总体：MCU 板—驱动板—电机三相线；SPI 接编码器，I2C 接 IMU，UART 接 USB 转串口；ADC 采电流与母线。分区说明：（1）功率与驱动 ATK-PD6010B；（2）MCU 最小系统与时钟；（3）电流采样与运放通道（标注 IU/IV/IW、VBUS）；（4）编码器 SPI（CLK/MISO/MOSI/CS）；（5）IMU I2C（SCL/SDA）。

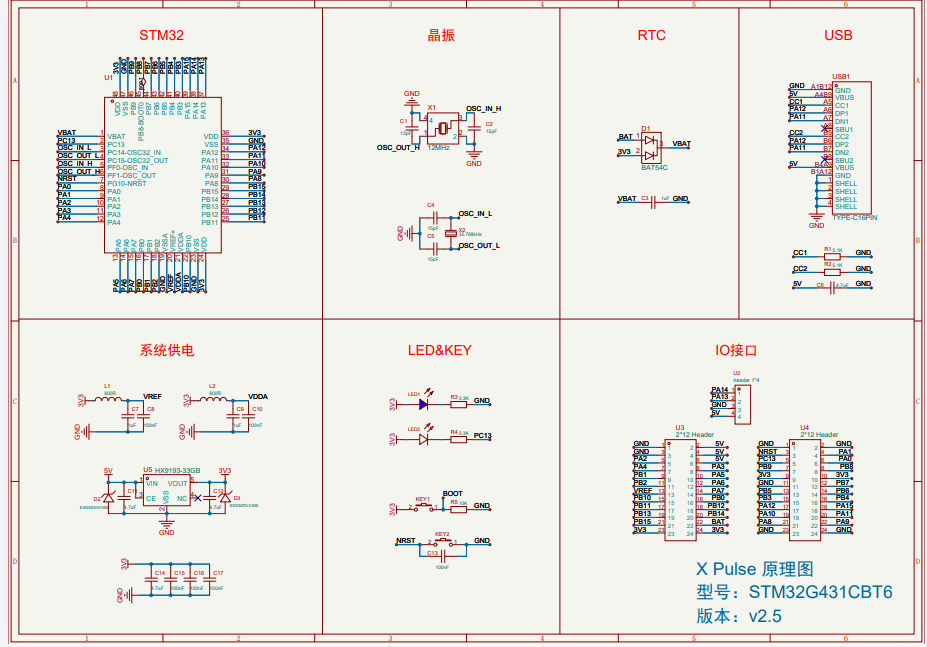
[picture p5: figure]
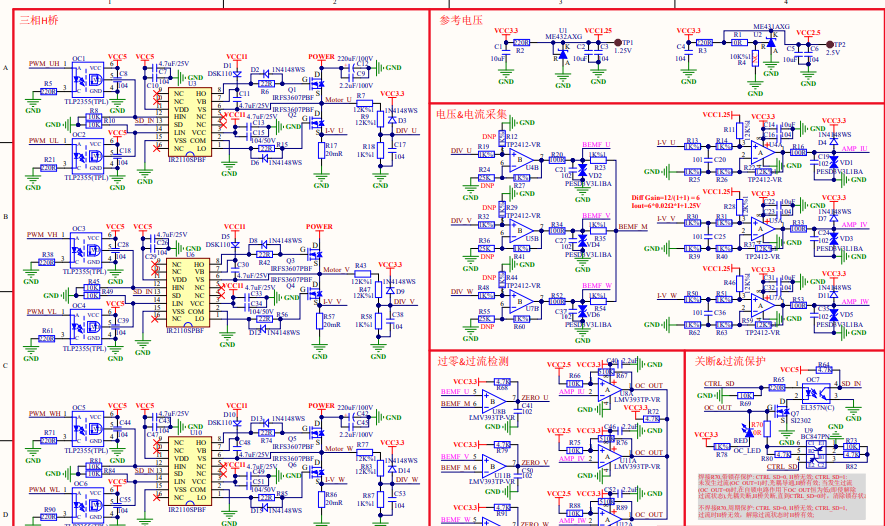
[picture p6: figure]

2.3软件系统介绍

2.3.1 软件整体介绍：软件分下位机固件（STM32G431CBT6_Motor/）、上位机工具（tmp/foc_ctl.py、foc_monitor.py、qt_host/）及离线仿真（MATLAB/Simulink）。固件基于 HAL + CMake 构建；应用层 app_control.c 负责状态机、模式切换、位置目标与自稳逻辑，foc_interface.c 负责 ISR 内测量、电流环 step 与保护，Simulink 生成 foc_controller.c。PC 端通过 USART3 @ 115200 与固件通信，接收 100 Hz CSV 遥测并下发单字符/行命令。Qt 图形上位机新增 qt_host 作为图形化调试与演示入口，采用 PySide6 构建桌面界面，pyserial 在独立 QThread 中完成串口收发，telemetry_parser.py 将固件输出的 T,... 遥测解析为结构化帧，pyqtgraph 以约 50 ms 刷新位置、Iq 与 IMU Pitch 曲线。界面左侧提供标准流程按钮（校准 a、使能 e、Home H、自稳 G）、速度滑块 S<dps>、直接力矩 I<amps> 与三连发急停 d；右侧显示系统状态、母线电压、位置误差、速度估计、编码器在线状态和串口日志。软件看门狗与 foc_ctl.py 保持相同保护思路，可在 FAULT、位置越界、速度异常或 Iq_ref 过大时自动下发停机命令。该上位机降低了演示和调参门槛，使故障定位从“串口文本观察”升级为“状态卡片 + 实时曲线 + 日志回显”的闭环工作流。

### 第三部分 完成情况及性能参数

3.1整体介绍

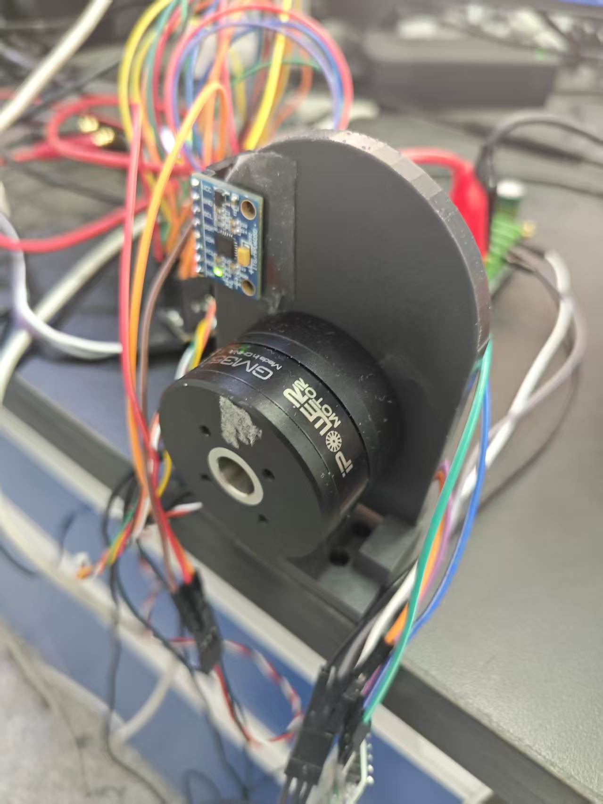
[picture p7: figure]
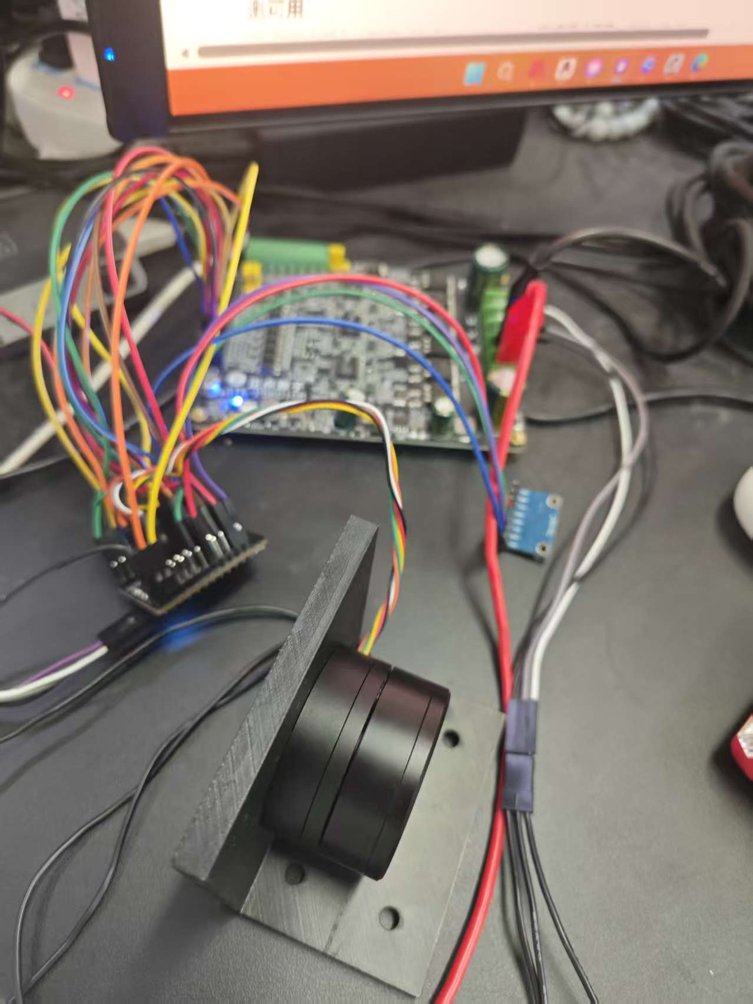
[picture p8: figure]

3.2工程成果：

3.2.1 机械成果3D 打印支架装配完成，电机轴与负载臂同轴度满足演示要求；自稳测试时底座可手动倾斜约 45°，臂端仍趋向水平。

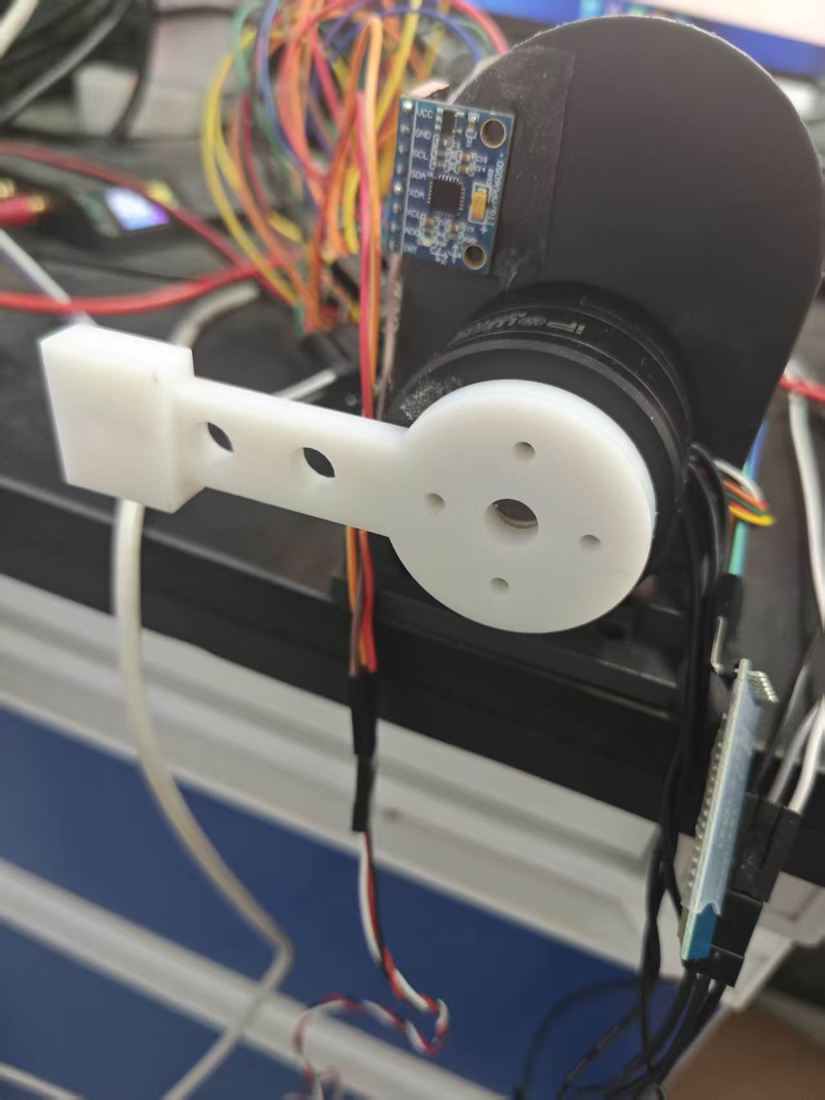
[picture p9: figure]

3.2.2 电路成果驱动板与 MCU 联调通过，三相 PWM 与电流采样正常；SPI 编码器、I2C IMU 通信稳定。

3.2.3 软件成果固件完成 ALIGN、RUN、SPEED、POSITION、STABILIZE、FAULT 等状态与控制模式，串口遥测稳定输出；命令行工具可复现实验流程；新增 Qt 图形上位机完成串口连接、T 帧解析、实时位置/Iq/IMU 曲线、标准流程控制、速度/力矩调试、状态卡片、日志回显和软件看门狗。

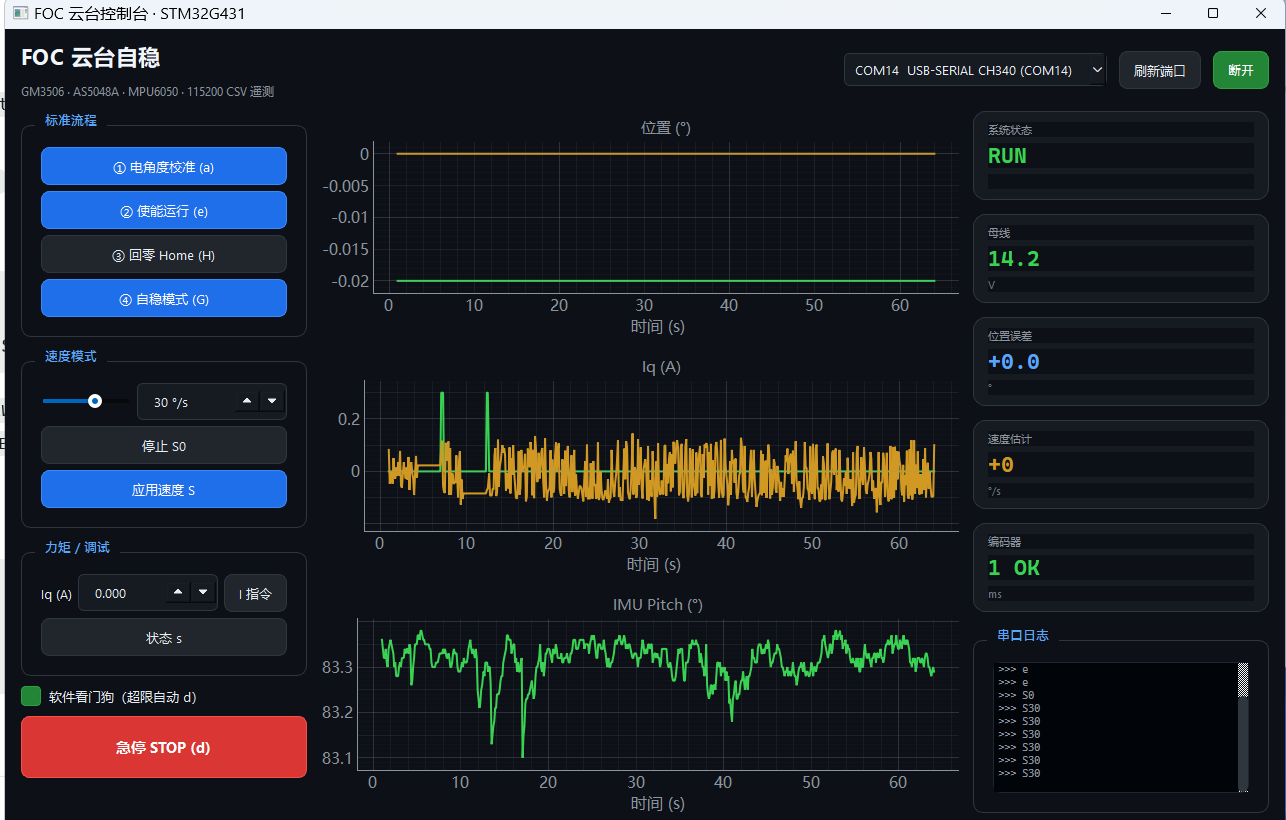
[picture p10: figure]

# 第四部分 总结

4.1可扩展之处:可扩展为双轴/三轴云台，增加第二路 FOC 与 yaw 轴编码器；引入 CAN/EtherCAT 替代 UART 便于工业组网；在位置环外增加视觉伺服（OpenMV/树莓派）实现目标跟踪；对 foc_params.m 做在线参数辨识适配不同电机；将 Qt 上位机扩展为参数下发、数据记录、曲线导出和故障回放平台；增加 FreeRTOS 划分通信与日志任务；机械上采用 CNC 支架提高刚度；安全方面完善编码器去抖、过温与硬件急停，满足更长时运行。

4.2心得体会:本作品从选题、仿真到下位机联调，完整走通了 STM32G4 电机控制链路。初期在电流采样符号、相序与 ADC 通道映射上花费较多时间，通过 FOC_DBG_FIXED_VECTOR 等分级调试手段逐相验证，体会到"先开环、再闭环、最后上负载"的必要性。Simulink 生成代码显著降低手写 PI 与限幅错误，但 ISR 时序与全局变量接口仍需严格约定，否则会出现积分饱和或抖动。ALIGN 与磁编安装高度相关，旋转校准 + 手动 F 微调命令提高了现场适应性。自稳模式将 IMU 与位置环结合，重力矩由积分项消化，分段 KP 则在远近误差下平衡快速性与平稳性。上位机脚本化演示极大方便竞赛展示，也暴露协议需防误触与看门狗的必要性。机械结构虽为 3D 打印，质心与轴系对齐对自稳效果影响明显，后续应在 CAD 阶段做简单动力学估算。整体而言，项目整合了意法半导体 MCU、FOC 算法、传感器融合与工程工具链，为工业 4.0 电机控制场景提供了可复现的原型平台；后续将在多轴协调、参数自整定与更长可靠性测试上继续完善。

# 第五部分 参考文献

[1] TI. Field Oriented Control of 3-Phase AC Motors[S]. Literature Number: SPRU723, 2013.

[2] ST Microelectronics. STM32G431xx Datasheet and Reference Manual[Z]. 2024.

[3] ST Microelectronics. AN1076: Sensorless Field Oriented Control of PMSM Motors[Z].

[4] ST Microelectronics. AN4680: Field-oriented control of PMSM driven by sensorless algorithm[Z].

[5] MathWorks. Embedded Coder User's Guide[R]. R2024b.

[6] ams OSRAM. AS5048A Magnetic Position Sensor Datasheet[Z].

[7] InvenSense. MPU-6000/6050 Product Specification[Z].

[8] Bose B K. Modern Power Electronics and AC Drives[M]. Prentice Hall, 2002.

[9] Mohan N. Power Electronics: A First Course[M]. Wiley, 2012.

[10] 王成元， 夏加宽， 杨俊友。 电机现代控制技术[M]. 北京： 机械工业出版社。

[11] 陈伯时。 电力拖动自动控制系统——运动控制系统[M]. 北京： 机械工业出版社。

[12] 全国大学生嵌入式芯片与系统设计竞赛2026竞赛指南（意法半导体赛道）[Z].

[13] ARM Ltd. CMSIS-DSP Software Library Documentation[Z].

[14] ST Microelectronics. STM32CubeG4 User Manual: TIM PWM Generation and ADC Injection[Z].

[15] Atkinson K E. Numerical Analysis for SVPWM Modulation Principles[M].

[16] Python Software Foundation. pyserial Documentation[Z].

[17] GitHub. STM32 HAL Driver Overview and Best Practices[Z].

[18] Wang J, et al. Permanent Magnet Synchronous Machine Model for Field-Oriented Control[C]. IEEE.

[19] ISO/IEC/IEEE 12207:2017 Systems and software engineering — Software life cycle processes[S].

[20] MIT License. Open Source Software Licensing[Z].

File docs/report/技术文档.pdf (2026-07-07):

## STM32G431 磁场定向控制单轴云台姿态自稳系统

摘要

本项目面向工业现场对轻载姿态保持与小功率伺服的需求，设计并实现了一套基于 STM32G431CBT6 的单轴云台磁场定向控制（FOC）自稳系统。系统以 GM3506 无刷 云台电机为执行机构，配合 ATK-PD6010B 三相驱动、AS5048A 磁编码器与 MPU6050 惯性测量单元，在 12 V 直流供电下完成电角度校准、闭环速度/位置控 制及 IMU 辅助水平自稳。

软件采用“模型设计 + 嵌入式部署 + 图形化调试”路线：电流环 PI 与 SVPWM 由 Simulink Embedded Coder 自动生成并在 20 kHz PWM-ADC 同步中断中执行； 位置环与自稳逻辑在应用层以约 1 kHz 更新，采用分段比例增益、微分阻尼与积 分项消除重力静差。系统具备 ALIGN 旋转式零位校准、串口命令调度、100 Hz 遥 测及母线电压/ADC 饱和等软件保护；PC 端除脚本化 foc_ctl.py 外，新增基于 PySide6 的 Qt 图形上位机，实现串口连接、实时曲线、标准流程按钮、速度/Iq 调节与软件看门狗，便于现场演示和联调。

经仿真与实物验证，电机可按指令正反转（如 ±40°/s、±100°/s），在底座倾 斜时进入自稳模式可保持负载臂相对水平。本作品将电机控制、传感器融合与工程 化工具链结合，具有结构清晰、参数可追溯、便于扩展多轴与视觉伺服等特点，适 用于巡检云台、教学科研中的 FOC 实践平台。

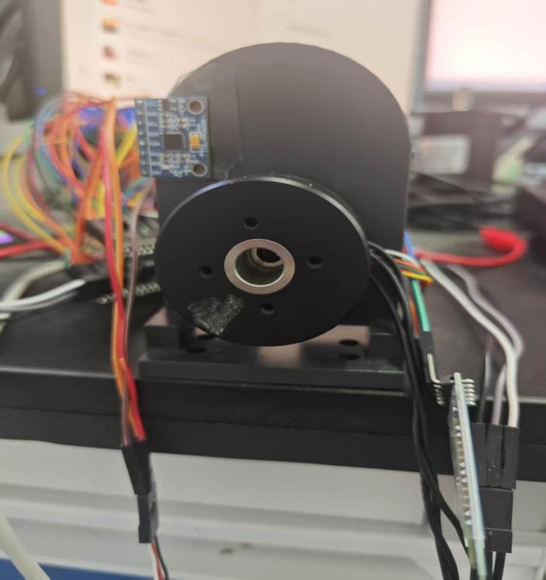
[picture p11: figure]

第一部分 作品概述

1.1 功能与特性：本系统实现单轴云台的 FOC 驱动与姿态自稳。主要功能包括： （1）电角度校准（ALIGN）：开环采样结合 π/2 修正与 Iq 脉冲方向校验，建立 可靠 dq 坐标；（2）运行模式：使能 RUN 后支持速度指令（S<dps>）、力矩注入 （I<A>）、开环换相测试（O/X）及零点设定（H）；（3）IMU 自稳（G）：将 MPU6050 俯仰角映射为位置目标，电机反向补偿使臂端保持水平；（4）安全与诊 断：母线 8–26 V 监测、ADC 饱和检测、速度超限切断、串口遥测与 dq 统计。

硬件上 MCU 170 MHz Cortex-M4 驱动 20 kHz 电流环；编码器 14 bit SPI 绝对 角；通信采用 UART 字符协议，PC 端既可用 foc_ctl.py 脚本化演示全流程，也 可通过 qt_host 图形上位机完成端口选择、遥测可视化、标准自稳流程控制、速 度/力矩调试和急停保护。

1.2 应用领域：工业 4.0 与机器人：单轴稳定平台可用于轻量传感器载体、管道/ 廊道巡检相机云台、协作机械臂末端调姿等，在载体晃动时维持视轴或工具姿态。 无人机与光电吊舱：原理可扩展至多轴万向节，为航拍、搜救提供稳像基础。新能 源与装备测试：FOC 平台可用于电机参数辨识、驱动算法对比及 HIL 前的快速原 型。教育与竞赛：覆盖 CubeMX 外设、Simulink 代码生成、CMake 交叉编译与现 场调试，契合嵌入式芯片与电机控制选题。

本方案强调低成本商用模块（GM3506、PD6010B、磁编）与开源工具链，便于实验 室复现与二次开发。

1.3 主要技术特点:（1）分层控制架构：电流环 20 kHz（Simulink 生成 PI + SVPWM），位置/自稳环 1 kHz（非线性 KP、KD、KI），职责清晰、易于调参。（2） 模型驱动开发：foc_controller.slx 与 foc_params.m 统一带宽（200 Hz）与限 幅，生成代码与 foc_interface.c ISR 无缝对接。（3）高精度角度链：AS5048A SPI 绝对编码 + 旋转校准，消除安装误差；IMU 提供重力参考实现外环补偿。（4） 工程化状态机：INIT→CALIBRATE→READY→RUN/FAULT，含零偏采集、对齐验证与 故障复位策略。（5）可观测性：100 Hz 遥测、Simulink 闭环仿真（foc_sim.slx） 及 Python 监控，缩短"仿真—下位机"迭代周期。（6）机械适配：gimbal_mount/ 提供 3D 打印支架 STL，便于快速搭建单轴演示台。

1.4 主要性能指标:

指标项 | 参数
主控 MCU | STM32G431CBT6，170 MHz
电机 | GM3506，11 极对

电流环执行频率 | 20 kHz
电流环设计带宽 | 200 Hz（Simulink PI）
编码器 | AS5048A，14 bit SPI
IMU | MPU6050，I2C
供电 | 12 V DC，母线保护 8–26 V
速度模式 | 指令示例 ±40°/s、±100°/s
速度保护 | 400°/s（ISR 切断力矩）
位置环输出限幅 | 约 45°/s（应用层）
遥测 | UART 100 Hz
上位机交互 | PySide6 图形界面；USART3 115200； 实时位置/Iq/IMU 曲线；流程按钮与软 件看门狗

1.5 主要创新点:

1. Simulink 电流环 + ISR 位置自稳：内环模型自动生成，外环针对重力静差定 制分段 KP 与积分，兼顾响应与平稳。
2. 旋转式 ALIGN 流程：结合开环角与编码器互校验，降低磁编安装误差对 FOC 的影响。 3. IMU—编码器双反馈自稳：俯仰角作位置目标，编码器闭环执行，底 座倾斜时仍保持水平。 4. 图形化上位机与脚本化调试并行：foc_ctl.py 支持一 键串联校准、使能、自稳，qt_host 基于 PySide6 提供实时位置/Iq/IMU 曲线、 流程按钮、速度滑块、力矩注入、三连发急停和软件看门狗，提升比赛现场演示与 故障定位效率。 5. 完整开源链路：CubeMX + CMake + Simulink ERT + Qt/Python 上位机 + 仿真图，参数与代码同源可追溯。

1.6 设计流程: 需求分析（单轴稳像、FOC）→ 电机与驱动选型 → Simulink 电流 环建模与 foc_sim.slx 闭环验证 → CubeMX 配置 TIM1/ADC/SPI/I2C/UART → 集 成 ERT 代码与 app_control 状态机 → 编码器/IMU 驱动与 ALIGN → 位置与自 稳联调 → 3D 打印机械件装配 → 串口协议、Python 脚本与 Qt 图形上位机开发 → 实物指标测试、遥测曲线核查与文档整理。


第二部分 系统组成及功能说明

2.1 整体介绍

系统由功率与驱动、传感、控制计算、人机交互四部分组成。12 V 经驱动板 ATK-PD6010B 逆变驱动 GM3506；STM32G431 通过 TIM1 输出 SVPWM，ADC 同步采样三 相电流与母线/温度；AS5048A 经 SPI 提供转子位置，MPU6050 经 I2C 提供姿态； UART 连接 PC 下发 a/e/H/G/S/I/d 等命令并上传 T,... CSV 遥测。人机交互层 包含命令行脚本与 Qt 图形上位机：脚本适合自动化复现实验，Qt 上位机适合比 赛现场连接、曲线观察、流程控制和急停保护。数据流：IMU pitch / 用户指令 → 位置目标 → ISR 级位置控制 → IqRef → FOC 电流环 → SVPWM → 三相驱 动 → 编码器/电流/IMU 反馈闭环。

2.2 硬件系统介绍

2.2.1 硬件整体介绍核心为 STM32G431CBT6 最小系统 + ATK-PD6010B 三相桥 + GM3506 电机；传感包括 AS5048A（轴端磁编）与 MPU6050（IMU 模块）；电源 12 V，逻辑 3.3 V。MCU 负责 PWM、电流采样、通信与实时算法；驱动板完成功率放 大与保护。整体为桌面级单轴演示平台，便于示波器测电流与串口观察状态。

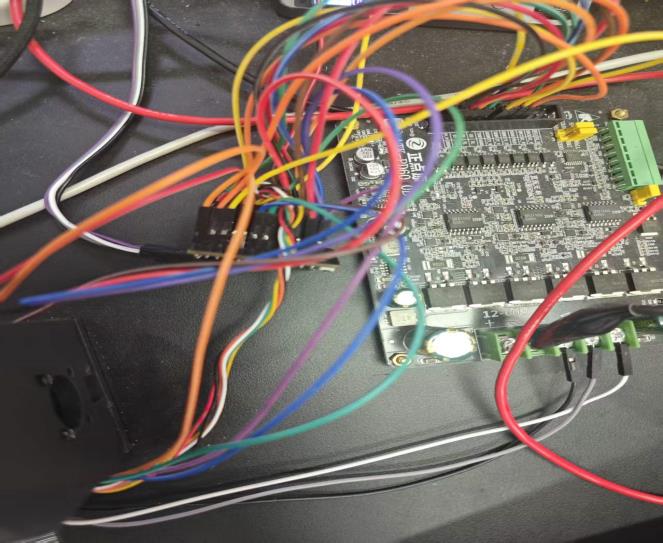
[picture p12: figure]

2.2.2 机械设计介绍：采用 gimbal_mount/ 中 3D 打印支架固定电机、IMU 与负 载臂，保证 IMU 与旋转轴关系稳定、负载质心接近轴心以减小重力矩。

2.2.3 电路各模块介绍总体：MCU 板—驱动板—电机三相线；SPI 接编码器，I2C 接 IMU，UART 接 USB 转串口；ADC 采电流与母线。分区说明：（1）功率与驱动 ATK-PD6010B；（2）MCU 最小系统与时钟；（3）电流采样与运放通道（标注 IU/IV/IW、VBUS）；（4）编码器 SPI（CLK/MISO/MOSI/CS）；（5）IMU I2C （SCL/SDA）。

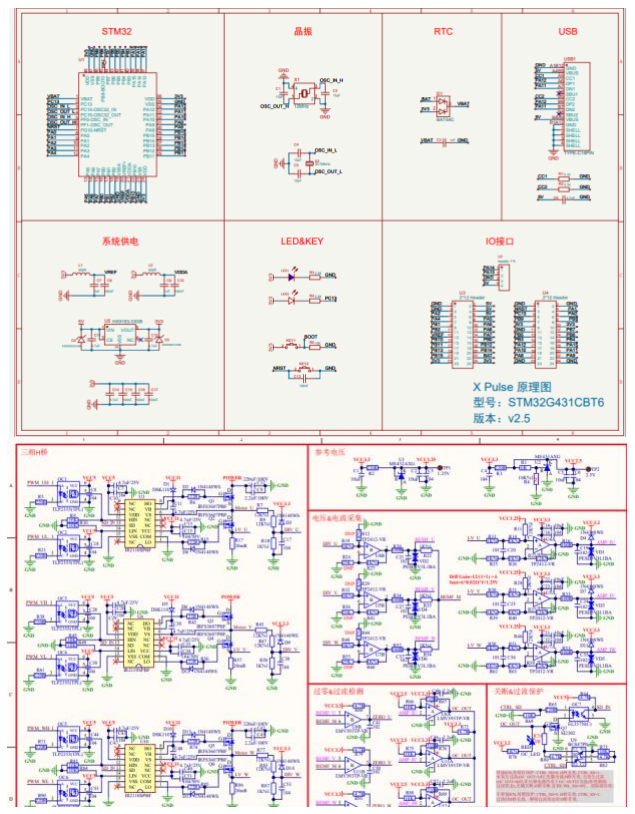
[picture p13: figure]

2.3 软件系统介绍

2.3.1 软件整体介绍：软件分下位机固件（STM32G431CBT6_Motor/）、上位机工具 （tmp/foc_ctl.py、foc_monitor.py、qt_host/）及离线仿真 （MATLAB/Simulink）。固件基于 HAL + CMake 构建；应用层 app_control.c 负 责状态机、模式切换、位置目标与自稳逻辑，foc_interface.c 负责 ISR 内测量、 电流环 step 与保护，Simulink 生成 foc_controller.c。PC 端通过 USART3 @ 115200 与固件通信，接收 100 Hz CSV 遥测并下发单字符/行命令。Qt 图形上位 机新增 qt_host 作为图形化调试与演示入口，采用 PySide6 构建桌面界面， pyserial 在独立 QThread 中完成串口收发，telemetry_parser.py 将固件输出的 T,... 遥测解析为结构化帧，pyqtgraph 以约 50 ms 刷新位置、Iq 与 IMU Pitch 曲线。界面左侧提供标准流程按钮（校准 a、使能 e、Home H、自稳 G）、速度滑 块 S<dps>、直接力矩 I<amps> 与三连发急停 d；右侧显示系统状态、母线电压、 位置误差、速度估计、编码器在线状态和串口日志。软件看门狗与 foc_ctl.py 保 持相同保护思路，可在 FAULT、位置越界、速度异常或 Iq_ref 过大时自动下发停 机命令。该上位机降低了演示和调参门槛，使故障定位从“串口文本观察”升级为 “状态卡片 + 实时曲线 + 日志回显”的闭环工作流。

第三部分 完成情况及性能参数

3.1 整体介绍

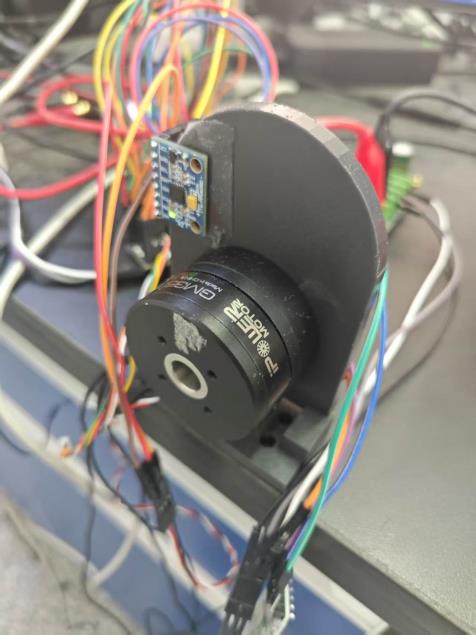
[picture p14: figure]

3.2 工程成果：

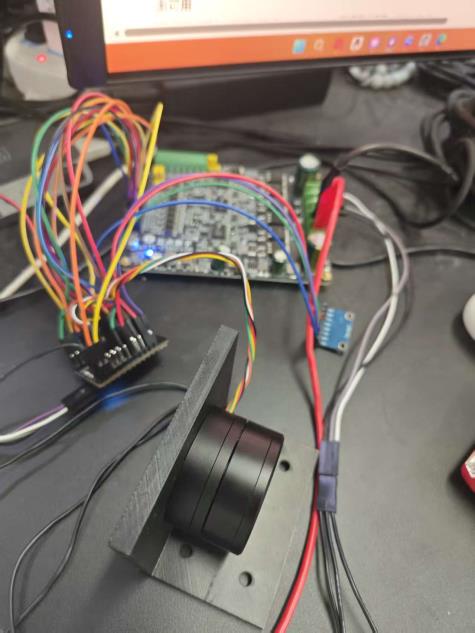
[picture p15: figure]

3.2.1 机械成果 3D 打印支架装配完成，电机轴与负载臂同轴度满足演示要求；自 稳测试时底座可手动倾斜约 45°，臂端仍趋向水平。

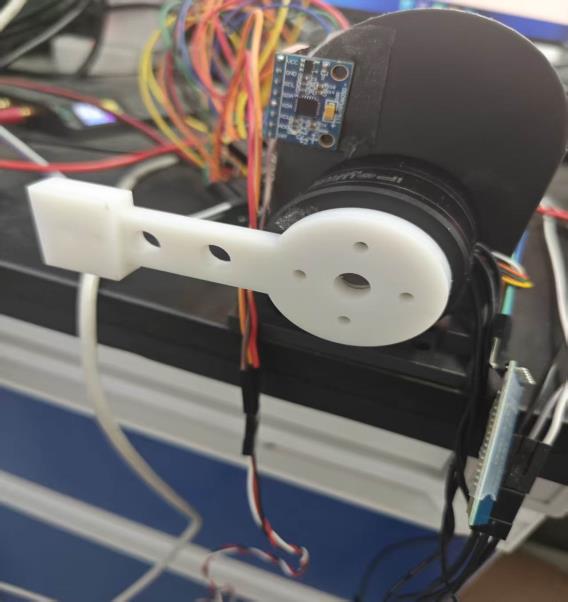
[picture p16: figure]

3.2.2 电路成果驱动板与 MCU 联调通过，三相 PWM 与电流采样正常；SPI 编码器、 I2C IMU 通信稳定。

3.2.3 软件成果固件完成 ALIGN、RUN、SPEED、POSITION、STABILIZE、FAULT 等 状态与控制模式，串口遥测稳定输出；命令行工具可复现实验流程；新增 Qt 图形

上位机完成串口连接、T 帧解析、实时位置/Iq/IMU 曲线、标准流程控制、速度/ 力矩调试、状态卡片、日志回显和软件看门狗。

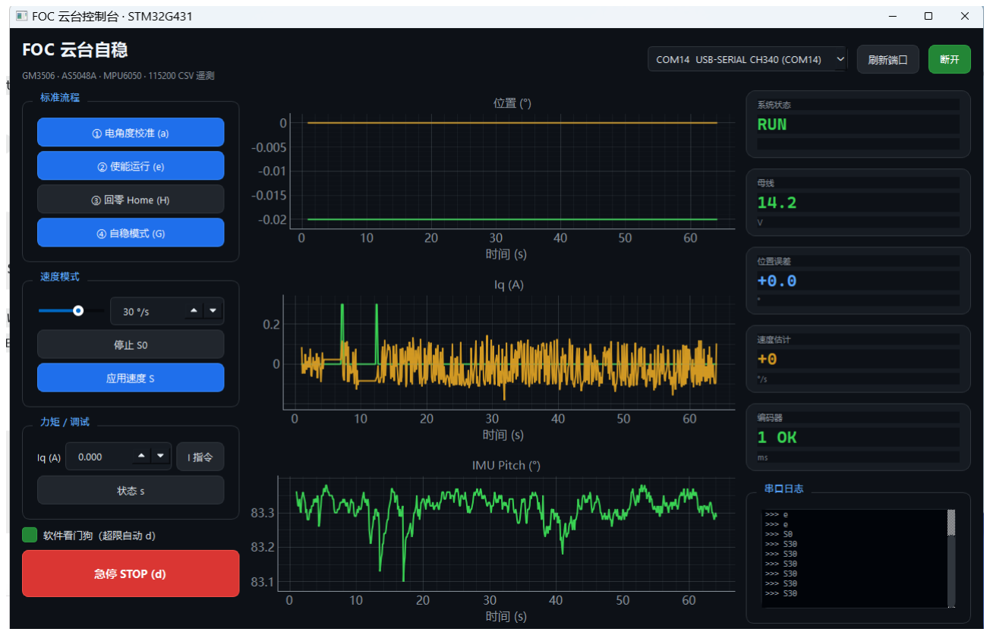
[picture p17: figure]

第四部分 总结

4.1 可扩展之处:可扩展为双轴/三轴云台，增加第二路 FOC 与 yaw 轴编码器；引 入 CAN/EtherCAT 替代 UART 便于工业组网；在位置环外增加视觉伺服（OpenMV/ 树莓派）实现目标跟踪；对 foc_params.m 做在线参数辨识适配不同电机；将 Qt 上位机扩展为参数下发、数据记录、曲线导出和故障回放平台；增加 FreeRTOS 划 分通信与日志任务；机械上采用 CNC 支架提高刚度；安全方面完善编码器去抖、 过温与硬件急停，满足更长时运行。

4.2 心得体会:本作品从选题、仿真到下位机联调，完整走通了 STM32G4 电机控制 链路。初期在电流采样符号、相序与 ADC 通道映射上花费较多时间，通过 FOC_DBG_FIXED_VECTOR 等分级调试手段逐相验证，体会到"先开环、再闭环、最后 上负载"的必要性。Simulink 生成代码显著降低手写 PI 与限幅错误，但 ISR 时 序与全局变量接口仍需严格约定，否则会出现积分饱和或抖动。ALIGN 与磁编安装 高度相关，旋转校准 + 手动 F 微调命令提高了现场适应性。自稳模式将 IMU 与 位置环结合，重力矩由积分项消化，分段 KP 则在远近误差下平衡快速性与平稳性。 上位机脚本化演示极大方便竞赛展示，也暴露协议需防误触与看门狗的必要性。机 械结构虽为 3D 打印，质心与轴系对齐对自稳效果影响明显，后续应在 CAD 阶段

做简单动力学估算。整体而言，项目整合了意法半导体 MCU、FOC 算法、传感器融 合与工程工具链，为工业 4.0 电机控制场景提供了可复现的原型平台；后续将在 多轴协调、参数自整定与更长可靠性测试上继续完善。

第五部分 参考文献

[1] TI. Field Oriented Control of 3-Phase AC Motors[S]. Literature Number: SPRU723, 2013.
[2] ST Microelectronics. STM32G431xx Datasheet and Reference Manual[Z]. 2024.
[3] ST Microelectronics. AN1076: Sensorless Field Oriented Control of PMSM Motors[Z].
[4] ST Microelectronics. AN4680: Field-oriented control of PMSM driven by sensorless algorithm[Z].
[5] MathWorks. Embedded Coder User's Guide[R]. R2024b.
[6] ams OSRAM. AS5048A Magnetic Position Sensor Datasheet[Z].
[7] InvenSense. MPU-6000/6050 Product Specification[Z].
[8] Bose B K. Modern Power Electronics and AC Drives[M]. Prentice Hall, 2002.
[9] Mohan N. Power Electronics: A First Course[M]. Wiley, 2012.
[10] 王成元， 夏加宽， 杨俊友。 电机现代控制技术[M]. 北京： 机械工业出版社。
[11] 陈伯时。 电力拖动自动控制系统——运动控制系统[M]. 北京： 机械工业出版社。
[12] 全国大学生嵌入式芯片与系统设计竞赛 2026 竞赛指南（意法半导体赛道）[Z].
[13] ARM Ltd. CMSIS-DSP Software Library Documentation[Z].
[14] ST Microelectronics. STM32CubeG4 User Manual: TIM PWM Generation and ADC Injection[Z].
[15] Atkinson K E. Numerical Analysis for SVPWM Modulation Principles[M].
[16] Python Software Foundation. pyserial Documentation[Z].
[17] GitHub. STM32 HAL Driver Overview and Best Practices[Z].
[18] Wang J, et al. Permanent Magnet Synchronous Machine Model for Field-Oriented Control[C]. IEEE.

[19] ISO/IEC/IEEE 12207:2017 Systems and software engineering — Software life cycle processes[S].
[20] MIT License. Open Source Software Licensing[Z].

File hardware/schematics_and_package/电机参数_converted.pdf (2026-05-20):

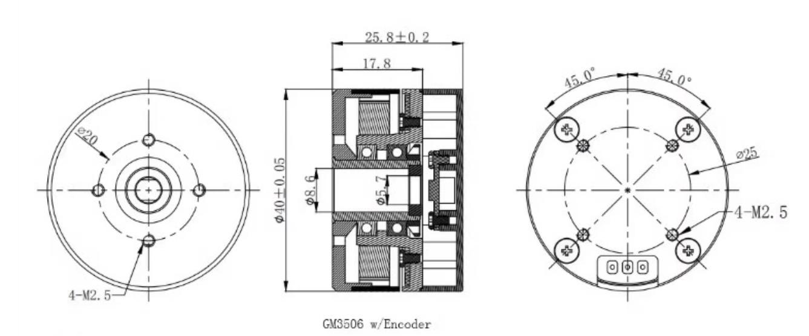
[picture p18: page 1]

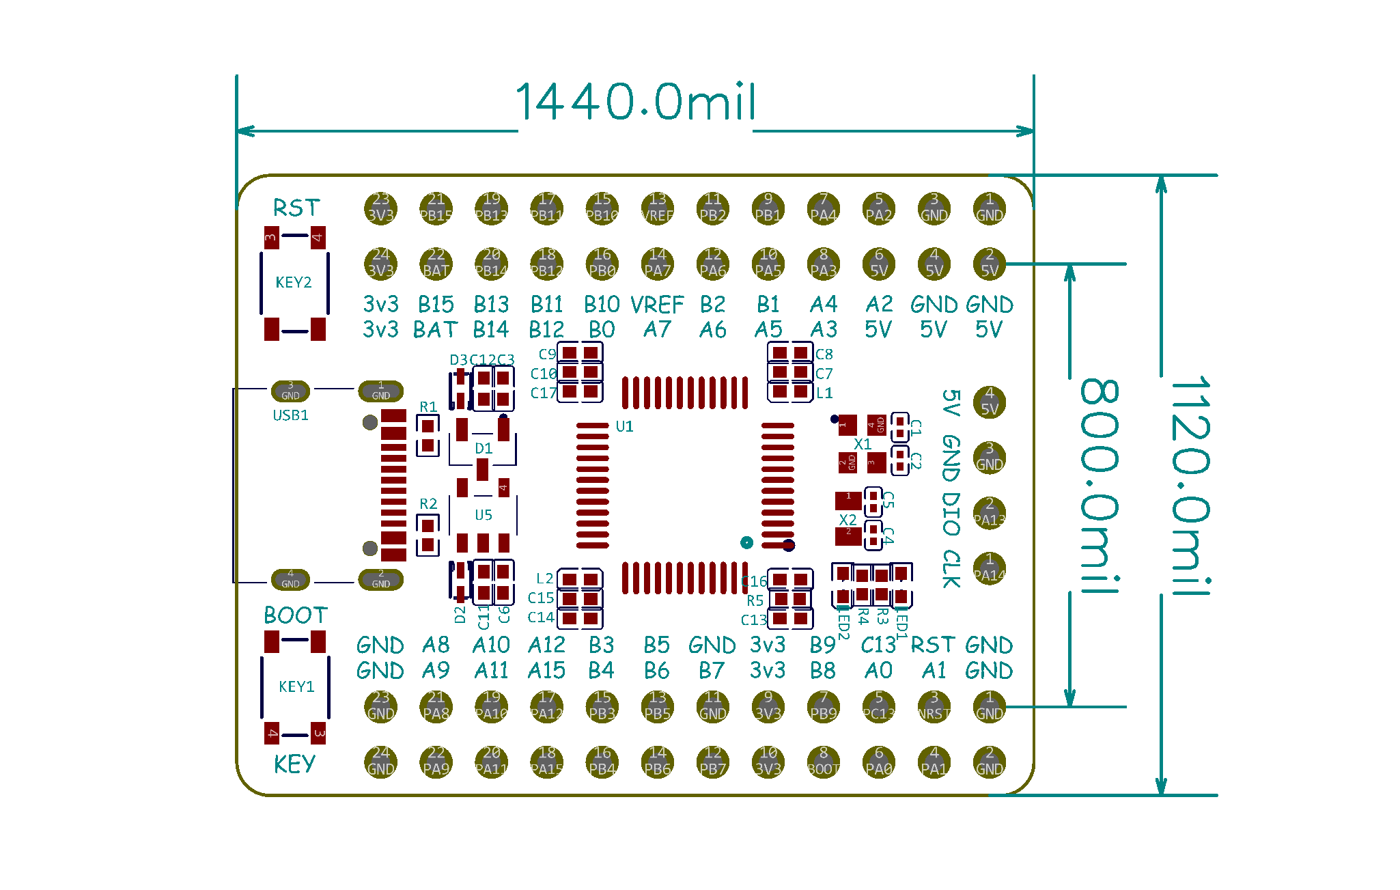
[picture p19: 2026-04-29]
hardware/schematics_and_package/主控芯片尺寸.png

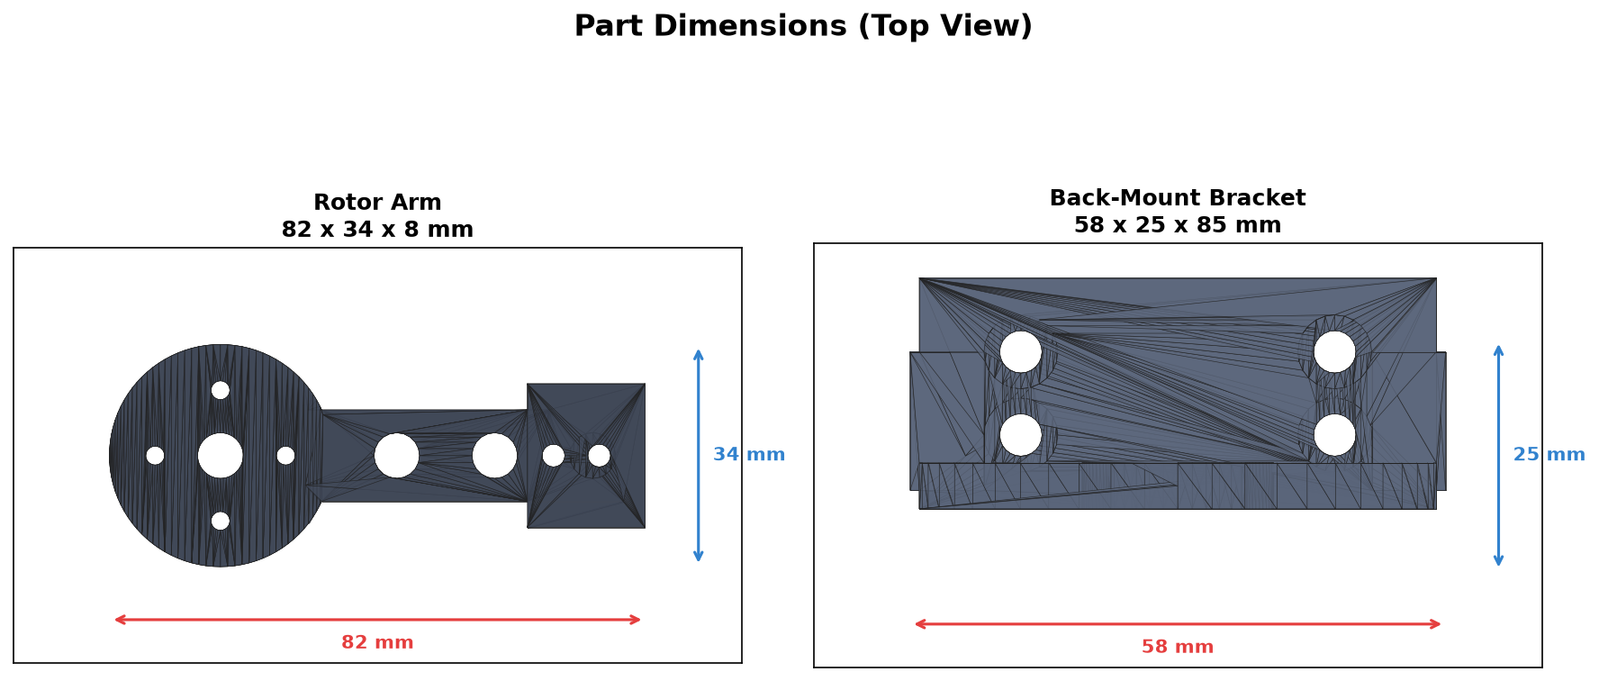
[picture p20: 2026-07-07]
hardware/gimbal_mount/dimensions.png

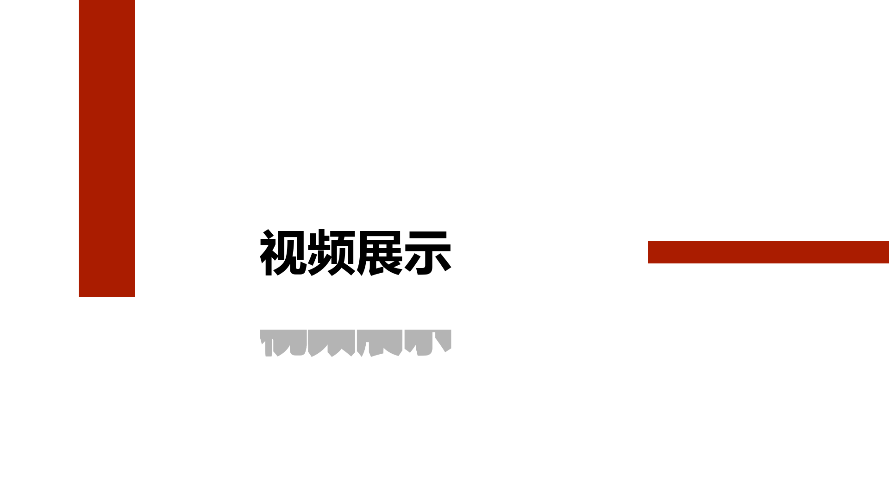
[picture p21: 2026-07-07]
docs/media/section_video_demo_simple.png

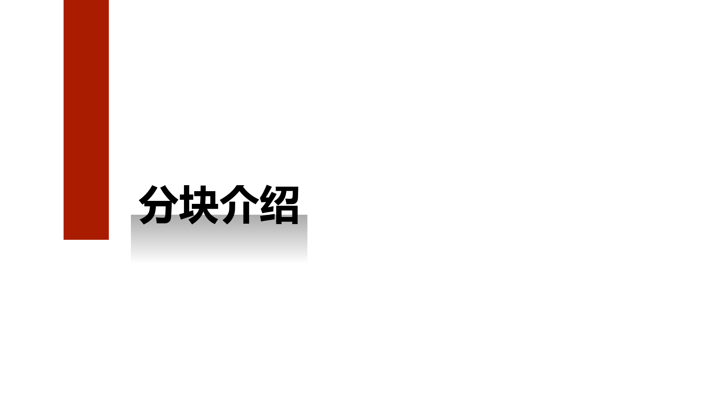
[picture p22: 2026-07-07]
docs/media/section_block_intro_simple.png

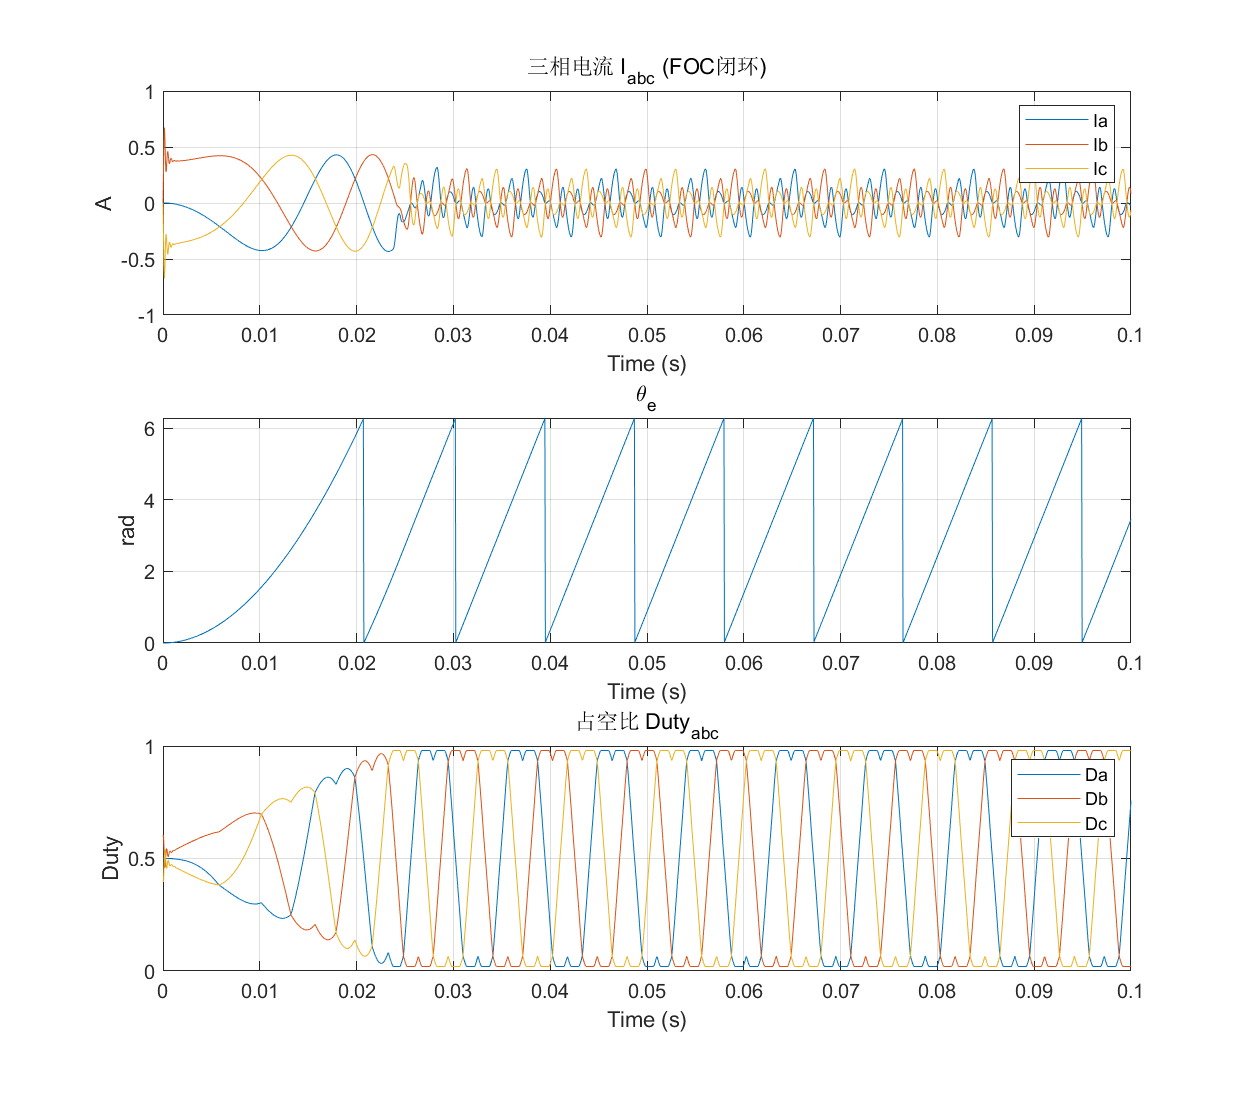
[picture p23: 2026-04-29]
docs/media/foc_closedloop.png

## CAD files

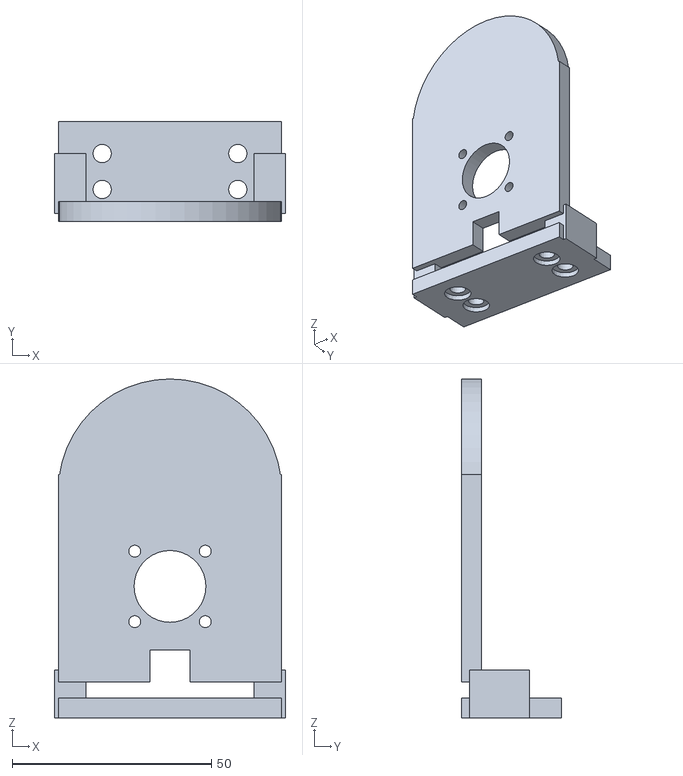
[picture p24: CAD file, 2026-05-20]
hardware/gimbal_mount/bracket.stl
58.0 x 25.0 x 85.0

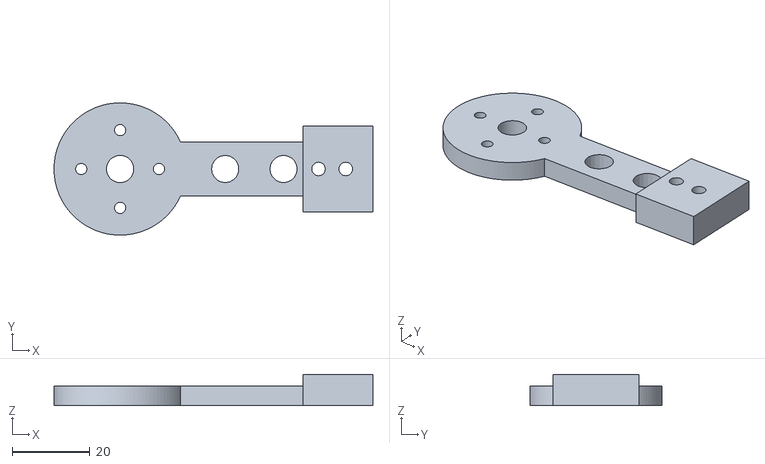
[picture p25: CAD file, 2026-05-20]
hardware/gimbal_mount/rotor_arm.stl
82.0 x 34.0 x 8.00

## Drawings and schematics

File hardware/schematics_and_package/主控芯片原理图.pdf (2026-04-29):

PB11 25 PB12 26 PB13 27 PB14 28 PB15 29 PA8 30 PA9 31 PA10 32 PA11 33 PA12 34 VSS 35 VDD 36 PA¹³ ³⁷

STM32 | 晶振 | RTC | USB

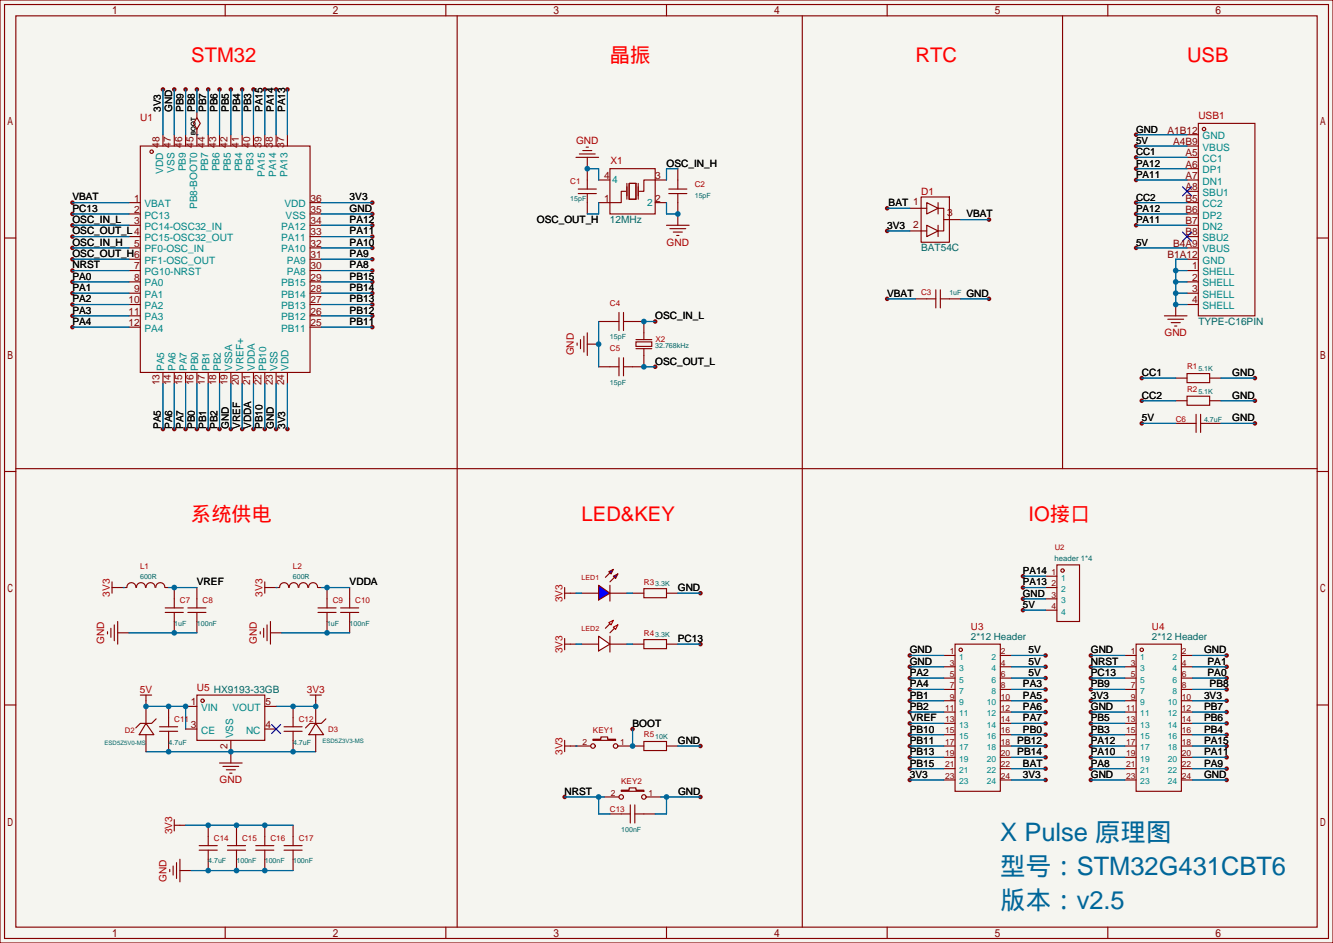
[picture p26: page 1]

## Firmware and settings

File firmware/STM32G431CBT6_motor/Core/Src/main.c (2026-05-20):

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
/* Includes ------------------------------------------------------------------*/
#include "main.h"
#include "adc.h"
#include "dma.h"
#include "tim.h"
#include "usart.h"
#include "gpio.h"

/* USER CODE BEGIN Includes */
#include <stdio.h>
#include <string.h>
#include <stdlib.h>
#include <math.h>
#include "app_control.h"
#include "encoder_spi.h"
#include "foc_interface.h"
#include "telemetry.h"
#include "mpu6050.h"       /* IMU 驱动（I2C1，CubeMX 使能后生效）*/
#include "openloop_stab.h" /* 开环自稳（临时方案，编码器修好后删除）*/
#include "board_config.h"  /* MOTOR_POLE_PAIRS */
#include "encoder_if.h"    /* encoder_get_angle_rad */
#include "spi.h"
/* 注意：CubeMX 生成 i2c.h 后下一行自动插入 */
/* USER CODE END Includes */


/* USER CODE BEGIN PV */
static uint16_t adc_raw_buffer[FOC_ADC_CH_COUNT]; // 5路采样
static uint8_t  rx_byte = 0;                       // 串口接收缓冲（单字节轮询）
/* USER CODE END PV */

void SystemClock_Config(void);
/* USER CODE BEGIN 0 */

/* ── USART3 RX 环形缓冲区（ISR 写头，主循环读尾，SPSC 无锁）── */
#define UART_RX_RING_MASK  (63U)
static volatile uint8_t s_rx_ring[64U];
static volatile uint8_t s_rx_head = 0U;
static volatile uint8_t s_rx_tail = 0U;

void serial_rx_push(uint8_t c)
{
    uint8_t next = (uint8_t)((s_rx_head + 1U) & UART_RX_RING_MASK);
    if (next != s_rx_tail) {
        s_rx_ring[s_rx_head] = c;
        s_rx_head = next;
    }
}

/* ── 行级命令解析 ── */

static bool parse_float(const char *s, float *out);  /* 前向声明 */

static void cmd_process_line(char *line)
{
    extern UART_HandleTypeDef huart3;
    static float cmd_omega_ref = 0.0f;
    static float cmd_iq_ref    = 0.0f;
    char resp[256];
    int  rlen = 0;

    static const char KNOWN_SINGLES[] = "edas+-][0EOXLQ";
    if (line[0] != '\0' && line[1] == '\0' &&
        strchr(KNOWN_SINGLES, line[0]) != NULL) {
        char c = line[0];
        switch (c) {
        case 'e':
            cmd_iq_ref = 0.0f; cmd_omega_ref = 0.0f;
            app_control_set_iq_ref(0.0f);
            app_control_set_speed_mode(false);
            if (app_control_enable())
                rlen = snprintf(resp, sizeof(resp), "[CMD] ENABLED, ST=%u\r\n", app_control_get_state());
            else {
                uint8_t st = app_control_get_state();
                FocMeasurement_t dbg_m; foc_interface_get_measurement(&dbg_m);
                rlen = snprintf(resp, sizeof(resp),
                    "[CMD] REJECT: ST=%u VBUS=%.1f ENC=%u\r\n",
                    st, dbg_m.vbus_v, encoder_is_valid() ? 1u : 0u);
            }
            break;
        case 'd':
            cmd_iq_ref = 0.0f; cmd_omega_ref = 0.0f;
            app_control_set_iq_ref(0.0f);
            app_control_disable();
            rlen = snprintf(resp, sizeof(resp), "[CMD] DISABLED, ST=%u\r\n", app_control_get_state());
            break;
        case 'a':
            cmd_omega_ref = 0.0f;
            app_control_set_speed_mode(false);
            if (app_control_start_align())
                rlen = snprintf(resp, sizeof(resp), "[CMD] ALIGN START, ST=%u\r\n", app_control_get_state());
            else {
                FocMeasurement_t dbg; foc_interface_get_measurement(&dbg);
                rlen = snprintf(resp, sizeof(resp), "[CMD] ALIGN REJECTED ST=%u VBUS=%.1f ENC=%u\r\n",
                    app_control_get_state(), dbg.vbus_v, encoder_is_valid() ? 1u : 0u);
            }
            break;
        case 's':
            rlen = snprintf(resp, sizeof(resp), "[CMD] ST=%u MODE=%u POS=%.2f TGT=%.2f\r\n",
                app_control_get_state(), (uint8_t)app_control_get_ctrl_mode(),
                app_control_get_pos_actual_deg(), app_control_get_pos_target_deg());
            break;
        case '+':
            app_control_set_speed_mode(false); cmd_omega_ref = 0.0f;
            cmd_iq_ref += 0.05f; if (cmd_iq_ref > 1.0f) cmd_iq_ref = 1.0f;
            app_control_set_iq_ref(cmd_iq_ref);
            rlen = snprintf(resp, sizeof(resp), "[CMD] IQ_REF=%.3f\r\n", cmd_iq_ref);
            break;
        case '-':
            app_control_set_speed_mode(false); cmd_omega_ref = 0.0f;
            cmd_iq_ref -= 0.05f; if (cmd_iq_ref < -1.0f) cmd_iq_ref = -1.0f;
            app_control_set_iq_ref(cmd_iq_ref);
            rlen = snprintf(resp, sizeof(resp), "[CMD] IQ_REF=%.3f\r\n", cmd_iq_ref);
            break;
        case ']':
            app_control_set_speed_mode(true);
            cmd_omega_ref += 0.5236f;
            app_control_set_omega_ref(cmd_omega_ref);
            rlen = snprintf(resp, sizeof(resp), "[CMD] SPD_REF=%.1f deg/s\r\n", cmd_omega_ref * 57.2958f);
            break;
        case '[':
            app_control_set_speed_mode(true);
            cmd_omega_ref -= 0.5236f;
            app_control_set_omega_ref(cmd_omega_ref);
            rlen = snprintf(resp, sizeof(resp), "[CMD] SPD_REF=%.1f deg/s\r\n", cmd_omega_ref * 57.2958f);
            break;
        case '0':
            app_control_set_speed_mode(true);
            cmd_omega_ref = 0.0f;
            app_control_set_omega_ref(0.0f);
            rlen = snprintf(resp, sizeof(resp), "[CMD] SPD_REF=0 (STOP)\r\n");
            break;
        case 'E': {
            uint16_t adc_snap[5];
            foc_interface_get_adc_raw(adc_snap);
            float offset = app_control_get_theta_offset();
            float mech = encoder_get_angle_rad();
            float mech_deg = mech * (180.0f / 3.14159265f);
            float elec_raw = encoder_get_elec_angle_rad(MOTOR_POLE_PAIRS);
            uint32_t isr_hz = foc_interface_get_isr_freq();
            float ea1 = elec_raw - offset;
            while (ea1 < 0) ea1 += 6.2832f;
            float ea2 = offset - elec_raw;
            while (ea2 < 0) ea2 += 6.2832f;
            int n = snprintf(resp, sizeof(resp),
                "[CMD] M=%.1f E=%.3f OFF=%.3f fwd=%.3f rev=%.3f ISR=%lu ADC=[%u,%u,%u]\r\n",
                mech_deg, elec_raw, offset, ea1, ea2,
                (unsigned long)isr_hz, adc_snap[0], adc_snap[1], adc_snap[2]);
            HAL_UART_Transmit(&huart3, (uint8_t*)resp, (uint16_t)n, 200);
            rlen = 0;
            break;
        }
        case 'O': {
            /* 开环测试：Vq=2V 克服齿槽，ω=5.5 rad/s 电角速 ≈ 0.5 rad/s 机械 ≈ 29°/s */
            HAL_GPIO_WritePin(GPIOB, GPIO_PIN_12, GPIO_PIN_SET); /* CTRL_SD 使能 */
            foc_openloop_start(5.5f, 2.0f);
            rlen = snprintf(resp, sizeof(resp), "[CMD] OPENLOOP ON w=5.5 Vq=2.0\r\n");
            break;
        }
        case 'X':
            openloop_stab_stop();   /* 先停自稳（内部会 stop openloop）*/
            foc_openloop_stop();    /* 确保纯开环模式也停 */
            HAL_GPIO_WritePin(GPIOB, GPIO_PIN_12, GPIO_PIN_RESET);
            rlen = snprintf(resp, sizeof(resp), "[CMD] OPENLOOP OFF\r\n");
            break;
        case 'L':
            if (mpu6050_is_ready()) {
                openloop_stab_start();
                rlen = snprintf(resp, sizeof(resp), "[CMD] OL_STAB ON\r\n");
            } else {
                rlen = snprintf(resp, sizeof(resp), "[CMD] OL_STAB FAIL: IMU not ready\r\n");
            }
            break;
        case 'Q': {
            float mech = encoder_get_angle_rad();
            float elec_raw = encoder_get_elec_angle_rad(MOTOR_POLE_PAIRS);
            float off = app_control_get_theta_offset();
            float ea1 = elec_raw - off;
            while (ea1 < 0) ea1 += 6.2832f;
            float ea2 = off - elec_raw;
            while (ea2 < 0) ea2 += 6.2832f;
            int n = snprintf(resp, sizeof(resp),
                "[ENC] M=%.3f E=%.3f off=%.3f fwd=%.3f rev=%.3f\r\n",
                mech, elec_raw, off, ea1, ea2);
            HAL_UART_Transmit(&huart3, (uint8_t*)resp, (uint16_t)n, 200);
            rlen = 0;
            break;
        }
        default: break;
        }
        goto send_resp;
    }

    /* B 切换 PI 旁路模式（RUN 时强制零电压输出，测 ADC 读数是否正确）*/
    if (line[0] == 'B') {
        static bool bp = false;
        bp = !bp;
        foc_interface_set_pi_bypass(bp);
        rlen = snprintf(resp, sizeof(resp),
            "[CMD] PI_BYPASS=%s\r\n", bp ? "ON(零电压)" : "OFF(正常)");
    }

    /* F<deg> 手动微调电角度偏移（运行中可改）*/
    if (line[0] == 'F') {
        float deg;
        if (parse_float(line + 1, &deg)) {
            float rad = deg * (3.14159265f / 180.0f);
            app_control_set_fine_offset(rad);
            rlen = snprintf(resp, sizeof(resp),
                "[CMD] FINE_OFF=%.0f deg (%.3f rad)\r\n", deg, rad);
        } else {
            rlen = snprintf(resp, sizeof(resp),
                "[CMD] FINE_OFF=%.1f deg\r\n",
                app_control_get_fine_offset() * (180.0f / 3.14159265f));
        }
    }

    /* I<amps> 直接设 IqRef 绕过速度环（运行中可改，用于测试电流环+角度）*/
    else if (line[0] == 'I' && (line[1] == '-' || line[1] == '+' || (line[1] >= '0' && line[1] <= '9'))) {
        float val;
        if (parse_float(line + 1, &val)) {
            /* 关闭速度模式，直接写 IqRef */
            app_control_set_speed_mode(false);
            app_control_set_iq_ref(val);
            rlen = snprintf(resp, sizeof(resp),
                "[CMD] IQ_DIRECT=%.3f A (速度环已关)\r\n", val);
        }
    }

    /* D: 编码器诊断——打印所有关键角度值 */
    if (line[0] == 'D' && line[1] == '\0') {
        float mech = encoder_get_angle_rad();
        float elec_raw = encoder_get_elec_angle_rad(MOTOR_POLE_PAIRS);
        float offset = app_control_get_theta_offset();
        float fine = app_control_get_fine_offset();
        float ea_fwd = elec_raw - offset + fine;
        while (ea_fwd < 0) ea_fwd += 6.2832f;
        while (ea_fwd >= 6.2832f) ea_fwd -= 6.2832f;
        float ea_rev = offset - elec_raw + fine;
        while (ea_rev < 0) ea_rev += 6.2832f;
        while (ea_rev >= 6.2832f) ea_rev -= 6.2832f;
        rlen = snprintf(resp, sizeof(resp),
            "[ENC] M=%.3f E=%.3f off=%.3f fwd=%.3f rev=%.3f\r\n",
            mech, elec_raw, offset, ea_fwd, ea_rev);
    }

    /* V<vq>: 编码器角度 + 直接电压（完全绕过 PI，决定性测试）
     * V2.0 = 启用，Vq=2V    V0 = 关闭 */
    if (line[0] == 'V' && (line[1] == '-' || line[1] == '+' || (line[1] >= '0' && line[1] <= '9'))) {
        float vq = 0.0f;
        parse_float(line + 1, &vq);
        if (fabsf(vq) > 0.01f) {
            foc_interface_set_bypass_vq(vq);
            foc_interface_set_pi_bypass(true);
            rlen = snprintf(resp, sizeof(resp),
                "[CMD] VDIRECT ON Vq=%.1f (PI bypass, encoder angle)\r\n", vq);
        } else {
            foc_interface_set_bypass_vq(0.0f);
            foc_interface_set_pi_bypass(false);
            rlen = snprintf(resp, sizeof(resp), "[CMD] VDIRECT OFF\r\n");
        }
    }

    /* C: 自动校准——开环旋转3秒，测量编码器关系 */
    if (line[0] == 'C' && line[1] == '\0') {
        foc_openloop_start(5.5f, 2.0f);
        HAL_Delay(3000);
        foc_openloop_stop();
        float avg_p, avg_m, enc_last;
        uint32_t cnt;
        foc_calib_get(&avg_p, &avg_m, &cnt, &enc_last);
        int n = snprintf(resp, sizeof(resp),
            "[CMD] CALIB N=%lu avg(OL+enc)=%.2f avg(OL-enc)=%.2f enc=%.2f\r\n",
            (unsigned long)cnt, avg_p, avg_m, enc_last);
        HAL_UART_Transmit(&huart3, (uint8_t*)resp, (uint16_t)n, 200);
        rlen = 0;
    }

    /* R<iq>: 强制闭环旋转（绕过编码器，纯PI电流环 + 固定角速度）
     * 用于验证除编码器外的完整FOC链路
     * R0.3 = 启动，Iq=0.3A
     * R0 或 R = 停止 */
    if (line[0] == 'R') {
        float iq = 0.0f;
        if (line[1] != '\0') parse_float(line + 1, &iq);
        if (fabsf(iq) > 0.01f) {
            app_control_set_speed_mode(false);
            app_control_set_iq_ref(iq);
            foc_forced_start(5.5f);  /* 5.5 rad/s 电角速度 */
            rlen = snprintf(resp, sizeof(resp),
                "[CMD] FORCED ON w=5.5 Iq=%.2f\r\n", iq);
        } else {
            foc_forced_stop();
            app_control_set_iq_ref(0.0f);
            rlen = snprintf(resp, sizeof(resp), "[CMD] FORCED OFF\r\n");
        }
    }

    /* T: 自动角度扫描——找到正确的电角度偏移 */
    if (line[0] == 'T' && line[1] == '\0') {
        if (app_control_get_state() != STATE_RUN) {
            rlen = snprintf(resp, sizeof(resp), "[CMD] T: need RUN state first\r\n");
        } else {
            float results[12];
            for (int step = 0; step < 12; step++) {
                float angle_rad = (float)step * 30.0f * 3.14159265f / 180.0f;
                app_control_set_fine_offset(angle_rad);
                app_control_set_iq_ref(0.0f);
                HAL_Delay(300);
                float m_before = encoder_get_angle_rad();
                app_control_set_iq_ref(0.5f);
                HAL_Delay(800);
                app_control_set_iq_ref(0.0f);
                float m_after = encoder_get_angle_rad();
                results[step] = (m_after - m_before) * (180.0f / 3.14159265f);
                HAL_Delay(400);
            }
            app_control_set_fine_offset(0.0f);
            /* 直接发送，用足够长的超时 */
            int n = snprintf(resp, sizeof(resp),
                "[CMD] SWEEP 0:%+.0f|30:%+.0f|60:%+.0f|90:%+.0f|120:%+.0f|150:%+.0f|"
                "180:%+.0f|210:%+.0f|240:%+.0f|270:%+.0f|300:%+.0f|330:%+.0f\r\n",
                results[0], results[1], results[2], results[3],
                results[4], results[5], results[6], results[7],
                results[8], results[9], results[10], results[11]);
            HAL_UART_Transmit(&huart3, (uint8_t*)resp, (uint16_t)n, 200);
            rlen = 0; /* 已发送，不走 send_resp */
        }
    }

    if (strcmp(line, "HTEST") == 0) {
        rlen = snprintf(resp, sizeof(resp), "[CMD] HTEST: hold=%.2f deg\r\n",
            app_control_get_pos_target_deg());
    }
    else if (strcmp(line, "H") == 0) {
        app_control_home();
        rlen = snprintf(resp, sizeof(resp), "[CMD] HOME OK, pos=%.2f->0, CTRL=POS\r\n",
            app_control_get_pos_actual_deg());
    }
    else if (strncmp(line, "PLIM", 4) == 0) {
        float val;
        if (parse_float(line + 4, &val)) {
            app_control_set_pos_spd_lim(val);
            rlen = snprintf(resp, sizeof(resp), "[CMD] POS_SPD_LIM=%.1f dps\r\n", app_control_get_pos_spd_lim());
        } else { rlen = snprintf(resp, sizeof(resp), "[CMD] PLIM: need 10-300\r\n"); }
    }
    else if (strncmp(line, "GLIM", 4) == 0) {
        /* GLIM<val>：设置自稳目标软限幅 [°]，默认10°，逐步放大到所需范围后再发G */
        float val;
        if (parse_float(line + 4, &val)) {
            app_control_set_stab_lim(val);
            rlen = snprintf(resp, sizeof(resp), "[CMD] STAB_LIM=%.1f deg\r\n", app_control_get_stab_lim());
        } else { rlen = snprintf(resp, sizeof(resp), "[CMD] GLIM: need 2-90\r\n"); }
    }
    else if (strncmp(line, "KP", 2) == 0) {
        float val;
        if (parse_float(line + 2, &val)) {
            app_control_set_kp_pos(val);
            rlen = snprintf(resp, sizeof(resp), "[CMD] KP_POS=%.3f\r\n", app_control_get_kp_pos());
        } else { rlen = snprintf(resp, sizeof(resp), "[CMD] KP: need 0-20\r\n"); }
    }
    else if (strncmp(line, "KD", 2) == 0) {
        float val;
        if (parse_float(line + 2, &val)) {
            app_control_set_kd_pos(val);
            rlen = snprintf(resp, sizeof(resp), "[CMD] KD_POS=%.4f\r\n", app_control_get_kd_pos());
        } else { rlen = snprintf(resp, sizeof(resp), "[CMD] KD: need 0-2\r\n"); }
    }
    else if (strncmp(line, "DZ", 2) == 0) {
        float val;
        if (parse_float(line + 2, &val)) {
            app_control_set_pos_deadband(val);
            rlen = snprintf(resp, sizeof(resp), "[CMD] DEADBAND=%.2f\r\n", app_control_get_pos_deadband());
        } else { rlen = snprintf(resp, sizeof(resp), "[CMD] DZ: need 0-5\r\n"); }
    }
    else if (strncmp(line, "STEP", 4) == 0) {
        float deg;
        if (parse_float(line + 4, &deg)) {
            app_control_set_pos_target(app_control_get_pos_target_deg() + deg);
            app_control_set_ctrl_mode(CTRL_POSITION);
            rlen = snprintf(resp, sizeof(resp), "[CMD] STEP+%.1f TGT=%.2f\r\n",
                deg, app_control_get_pos_target_deg());
        } else { rlen = snprintf(resp, sizeof(resp), "[CMD] STEP: need numeric\r\n"); }
    }
    else if (strcmp(line, "G") == 0) {
        /* G：切换到 CTRL_STABILIZE 自稳模式（需 IMU 就绪）*/
        if (mpu6050_is_ready()) {
            app_control_set_ctrl_mode(CTRL_STABILIZE);
            rlen = snprintf(resp, sizeof(resp), "[CMD] STABILIZE ON\r\n");
        } else {
            rlen = snprintf(resp, sizeof(resp), "[CMD] IMU not ready\r\n");
        }
    }
    else if (line[0] == 'S' && line[1] != '\0') {
        float dps;
        if (parse_float(line + 1, &dps)) {
            cmd_omega_ref = dps * (3.14159265f / 180.0f);
            app_control_set_speed_mode(true);
            app_control_set_omega_ref(cmd_omega_ref);
            rlen = snprintf(resp, sizeof(resp), "[CMD] SPD_MODE REF=%.1f dps\r\n", dps);
        } else { rlen = snprintf(resp, sizeof(resp), "[CMD] S: need numeric dps\r\n"); }
    }
    else if (line[0] == 'T' && line[1] != '\0') {
        /* 开环力矩：直接设 IqRef，绕过速度PI，用于隔离验证 */
        float iq;
        if (parse_float(line + 1, &iq)) {
            if (iq > 0.45f) iq = 0.45f;
            if (iq < -0.45f) iq = -0.45f;
            app_control_set_speed_mode(false);   /* 关闭速度PI */
            cmd_iq_ref = iq;
            app_control_set_iq_ref(iq);
            rlen = snprintf(resp, sizeof(resp), "[CMD] TORQUE IQ=%.3f A\r\n", iq);
        } else { rlen = snprintf(resp, sizeof(resp), "[CMD] T: need current [A]\r\n"); }
    }
    else if (line[0] == 'P') {
        float deg;
        if (parse_float(line + 1, &deg)) {
            app_control_set_pos_target(deg);
            app_control_set_ctrl_mode(CTRL_POSITION);
            rlen = snprintf(resp, sizeof(resp), "[CMD] POS_TGT=%.2f\r\n",
                app_control_get_pos_target_deg());
        } else { rlen = snprintf(resp, sizeof(resp), "[CMD] P: need angle\r\n"); }
    }

send_resp:
    if (rlen > 0) {
        HAL_UART_Transmit(&huart3, (uint8_t *)resp, (uint16_t)rlen, 5U);
    }
}

static uint8_t rx_buf[40];
static uint8_t rx_len = 0;

static bool parse_float(const char *s, float *out)
{
    char *ep;
    *out = strtof(s, &ep);
    if (ep == s) return false;
    while (*ep == ' ' || *ep == '\t') ep++;
    if (*ep != '\0') return false;
    if (!isfinite(*out)) return false;
    return true;
}

static void cmd_feed_byte(uint8_t c)
{
    static const char IMMEDIATE[] = "edas+-][0EOXL";
    if (rx_len == 0 && strchr(IMMEDIATE, (char)c)) {
        char line[2] = {(char)c, '\0'};
        cmd_process_line(line);
        return;
    }
    if (c == '\r' || c == '\n') {
        if (rx_len > 0) {
            rx_buf[rx_len] = '\0';
            cmd_process_line((char *)rx_buf);
            rx_len = 0;
        }
        return;
    }
    if (rx_len < sizeof(rx_buf) - 1) {
        rx_buf[rx_len++] = c;
    }
}

/* USER CODE END 0 */

/**
  * @brief  The application entry point.
  * @retval int
  */
int main(void)
{

  /* MCU Configuration--------------------------------------------------------*/

  /* Reset of all peripherals, Initializes the Flash interface and the Systick. */
  HAL_Init();

  /* Configure the system clock */
  SystemClock_Config();

  /* Initialize all configured peripherals */
  MX_GPIO_Init();
  MX_DMA_Init();
  MX_ADC1_Init();
  MX_TIM1_Init();
  MX_TIM2_Init();
  MX_USART3_UART_Init();
  __HAL_RCC_SPI1_CLK_ENABLE();  /* 确保 SPI1 时钟在 Init 前已开 */
  MX_SPI1_Init();
  /* USER CODE BEGIN 2 */
  // 1. 初始化各应用模块
  foc_interface_init();
  encoder_spi_init();
  app_control_init();
  telemetry_init();
  /* IMU 初始化（CubeMX 生成 MX_I2C1_Init 并在此之前调用后，此处有效）
   * 若 I2C 尚未配置则函数内部直接返回 false，不影响启动 */
  mpu6050_init();

  // 2. ADC 自校准（G4 必须在 Start 前执行，消除内部偏移误差）
  HAL_ADCEx_Calibration_Start(&hadc1, ADC_SINGLE_ENDED);

  // 3. 挂好数据接收方
  HAL_ADC_Start_DMA(&hadc1, (uint32_t*)adc_raw_buffer, FOC_ADC_CH_COUNT);

  // 3. 起振全电源桥臂 (底层内含 MOE 置位)
  HAL_TIM_PWM_Start(&htim1, TIM_CHANNEL_1);
  HAL_TIM_PWM_Start(&htim1, TIM_CHANNEL_2);
  HAL_TIM_PWM_Start(&htim1, TIM_CHANNEL_3);
  HAL_TIMEx_PWMN_Start(&htim1, TIM_CHANNEL_1);
  HAL_TIMEx_PWMN_Start(&htim1, TIM_CHANNEL_2);
  HAL_TIMEx_PWMN_Start(&htim1, TIM_CHANNEL_3);

  // 4. 最后拉开枪栓，放出内部触发源

  HAL_TIM_PWM_Start(&htim1, TIM_CHANNEL_4);

  // 5. 使能 USART3 RXNE 中断（绕过主循环 TX 阻塞，零丢字节）
  //    优先级 3：低于 FOC ADC ISR(0-1)，高于 SysTick(15)
  HAL_NVIC_SetPriority(USART3_IRQn, 3, 0);
  HAL_NVIC_EnableIRQ(USART3_IRQn);
  __HAL_UART_ENABLE_IT(&huart3, UART_IT_RXNE);
  /* USER CODE END 2 */

  /* Infinite loop */
  /* USER CODE BEGIN WHILE */
  while (1)
  {
    /* 主循环消费 RX 环形缓冲区（字节已由 USART3_IRQHandler ISR 填入）*/
    while (s_rx_tail != s_rx_head) {
        uint8_t c = s_rx_ring[s_rx_tail];
        s_rx_tail = (uint8_t)((s_rx_tail + 1U) & UART_RX_RING_MASK);
        cmd_feed_byte(c);
    }
    app_control_update();

    /* IMU 10ms 定时更新（轮询，不占 ISR）*/
    static uint32_t s_imu_last_ms = 0;
    uint32_t now_ms = HAL_GetTick();
    if (now_ms - s_imu_last_ms >= 10U) {
        s_imu_last_ms = now_ms;
        mpu6050_update();
    }

    openloop_stab_update();  /* 开环自稳 PD 控制（未激活时零开销）*/
    telemetry_update();
    /* USER CODE END WHILE */

    /* USER CODE BEGIN 3 */
  }
  /* USER CODE END 3 */
}

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
/* USER CODE BEGIN 4 */
void HAL_ADC_ConvCpltCallback(ADC_HandleTypeDef *hadc) {
    if (hadc == &hadc1) {
        /* 验证2: Pulse 首 */
        HAL_GPIO_WritePin(TEST_PIN_GPIO_Port, TEST_PIN_Pin, GPIO_PIN_SET);

        static uint16_t enc_div = 0;
        if (++enc_div >= 20U) {
            enc_div = 0;
            encoder_spi_read_isr();
        }

        foc_interface_step(adc_raw_buffer);

        /* 验证2: Pulse 尾 */
        HAL_GPIO_WritePin(TEST_PIN_GPIO_Port, TEST_PIN_Pin, GPIO_PIN_RESET);
    }
}

/* USER CODE END 4 */
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


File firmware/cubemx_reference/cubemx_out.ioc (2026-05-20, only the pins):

Mcu.UserName=STM32G431CBTx
PA0.Signal=ADC1_IN1
PA1.Signal=ADC1_IN2
PA10.Signal=S_TIM1_CH3
PA15.Signal=S_TIM2_CH1
PA2.Signal=ADC1_IN3
PA3.Signal=ADC1_IN4
PA4.GPIO_Label=ENC_CS
PA4.Signal=GPIO_Output
PA5.Signal=SPI1_SCK
PA6.Signal=SPI1_MISO
PA7.Signal=SPI1_MOSI
PA8.Signal=S_TIM1_CH1
PA9.Signal=S_TIM1_CH2
PB0.Signal=ADC1_IN15
PB10.Signal=USART3_TX
PB11.Signal=USART3_RX
PB12.Signal=GPIO_Output
PB13.Signal=TIM1_CH1N
PB14.Signal=TIM1_CH2N
PB15.Signal=TIM1_CH3N
PC13.GPIO_Label=TEST_PIN
PC13.Signal=GPIO_Output
PF0-OSC_IN.Signal=RCC_OSC_IN
PF1-OSC_OUT.Signal=RCC_OSC_OUT

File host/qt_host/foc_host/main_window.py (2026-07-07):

"""Main window — FOC Gimbal Host."""
from __future__ import annotations

import time
from collections import deque

import numpy as np
import pyqtgraph as pg
from PySide6.QtCore import Qt, QTimer, Signal, Slot
from PySide6.QtWidgets import (
    QCheckBox,
    QComboBox,
    QDoubleSpinBox,
    QFrame,
    QGridLayout,
    QGroupBox,
    QHBoxLayout,
    QLabel,
    QMainWindow,
    QPlainTextEdit,
    QPushButton,
    QSlider,
    QSpinBox,
    QVBoxLayout,
    QWidget,
)

from .serial_worker import SerialWorker, SerialThread
from .telemetry_parser import TelemetryFrame
from .theme import ACCENT_AMBER, ACCENT_BLUE, ACCENT_CYAN, ACCENT_RED, PLOT_BG, PLOT_FG, STYLESHEET


class MetricCard(QFrame):
    def __init__(self, title: str, unit: str = "", parent=None) -> None:
        super().__init__(parent)
        self.setObjectName("card")
        lay = QVBoxLayout(self)
        lay.setContentsMargins(14, 10, 14, 10)
        t = QLabel(title)
        t.setStyleSheet(f"color: {PLOT_FG}; font-size: 11px;")
        self._val = QLabel("—")
        self._val.setObjectName("metricValue")
        self._val.setStyleSheet(f"color: {ACCENT_CYAN}; font-size: 22px;")
        u = QLabel(unit)
        u.setObjectName("metricUnit")
        lay.addWidget(t)
        lay.addWidget(self._val)
        lay.addWidget(u)

    def set_value(self, text: str, color: str | None = None) -> None:
        self._val.setText(text)
        if color:
            self._val.setStyleSheet(f"color: {color}; font-size: 22px; font-weight: 700;")


class MainWindow(QMainWindow):
    emergency_stop = Signal()

    def __init__(self) -> None:
        super().__init__()
        self.setWindowTitle("FOC 云台控制台 · STM32G431")
        self.resize(1280, 800)
        self.setStyleSheet(STYLESHEET)

        pg.setConfigOptions(antialias=True, background=PLOT_BG, foreground=PLOT_FG)

        self._history_len = 600
        self._t0: float | None = None
        self._t_hist: deque[float] = deque(maxlen=self._history_len)
        self._pos_act: deque[float] = deque(maxlen=self._history_len)
        self._pos_tgt: deque[float] = deque(maxlen=self._history_len)
        self._imu: deque[float] = deque(maxlen=self._history_len)
        self._iq_ref: deque[float] = deque(maxlen=self._history_len)
        self._iq_meas: deque[float] = deque(maxlen=self._history_len)
        self._spd: deque[float] = deque(maxlen=self._history_len)

        self._last_frame: TelemetryFrame | None = None
        self._watchdog_enabled = True

        self._worker = SerialWorker()
        self._thread = SerialThread(self._worker)
        self._worker.moveToThread(self._thread)
        self._thread.start()

        self._build_ui()
        self._wire_signals()

        self._plot_timer = QTimer(self)
        self._plot_timer.setInterval(50)
        self._plot_timer.timeout.connect(self._refresh_plots)

    def _build_ui(self) -> None:
        central = QWidget()
        self.setCentralWidget(central)
        root = QVBoxLayout(central)
        root.setContentsMargins(16, 12, 16, 16)
        root.setSpacing(12)

        # Header
        header = QHBoxLayout()
        title_col = QVBoxLayout()
        title = QLabel("FOC 云台自稳")
        title.setObjectName("titleLabel")
        sub = QLabel("GM3506 · AS5048A · MPU6050 · 115200 CSV 遥测")
        sub.setObjectName("subtitleLabel")
        title_col.addWidget(title)
        title_col.addWidget(sub)
        header.addLayout(title_col)
        header.addStretch()

        self._port_combo = QComboBox()
        self._port_combo.setMinimumWidth(160)
        self._btn_refresh_ports = QPushButton("刷新端口")
        self._btn_connect = QPushButton("连接")
        self._btn_connect.setObjectName("primaryBtn")
        header.addWidget(self._port_combo)
        header.addWidget(self._btn_refresh_ports)
        header.addWidget(self._btn_connect)
        root.addLayout(header)

        body = QHBoxLayout()
        body.setSpacing(14)

        # Left — controls
        left = QVBoxLayout()
        left.setSpacing(10)

        flow = QGroupBox("标准流程")
        fl = QVBoxLayout(flow)
        btn_align = QPushButton("① 电角度校准 (a)")
        btn_align.setObjectName("accentBtn")
        btn_enable = QPushButton("② 使能运行 (e)")
        btn_enable.setObjectName("accentBtn")
        btn_home = QPushButton("③ 回零 Home (H)")
        btn_stab = QPushButton("④ 自稳模式 (G)")
        btn_stab.setObjectName("accentBtn")
        for b in (btn_align, btn_enable, btn_home, btn_stab):
            fl.addWidget(b)
        btn_align.clicked.connect(lambda: self._send("a"))
        btn_enable.clicked.connect(lambda: self._send("e"))
        btn_home.clicked.connect(lambda: self._send("H"))
        btn_stab.clicked.connect(lambda: self._send("G"))
        left.addWidget(flow)

        spd_g = QGroupBox("速度模式")
        sg = QVBoxLayout(spd_g)
        row = QHBoxLayout()
        self._spd_slider = QSlider(Qt.Horizontal)
        self._spd_slider.setRange(-120, 120)
        self._spd_slider.setValue(0)
        self._spd_spin = QSpinBox()
        self._spd_spin.setRange(-300, 300)
        self._spd_spin.setSuffix(" °/s")
        row.addWidget(self._spd_slider, 1)
        row.addWidget(self._spd_spin)
        sg.addLayout(row)
        btn_s0 = QPushButton("停止 S0")
        btn_s_apply = QPushButton("应用速度 S")
        btn_s_apply.setObjectName("accentBtn")
        sg.addWidget(btn_s0)
        sg.addWidget(btn_s_apply)
        self._spd_slider.valueChanged.connect(self._spd_spin.setValue)
        self._spd_spin.valueChanged.connect(self._spd_slider.setValue)
        btn_s0.clicked.connect(lambda: self._apply_speed(0))
        btn_s_apply.clicked.connect(lambda: self._apply_speed(self._spd_spin.value()))
        left.addWidget(spd_g)

        tor_g = QGroupBox("力矩 / 调试")
        tg = QGridLayout(tor_g)
        self._iq_spin = QDoubleSpinBox()
        self._iq_spin.setRange(-0.45, 0.45)
        self._iq_spin.setSingleStep(0.05)
        self._iq_spin.setDecimals(3)
        tg.addWidget(QLabel("Iq (A)"), 0, 0)
        tg.addWidget(self._iq_spin, 0, 1)
        btn_i = QPushButton("I 指令")
        btn_i.clicked.connect(lambda: self._send(f"I{self._iq_spin.value():.3f}"))
        tg.addWidget(btn_i, 0, 2)
        btn_status = QPushButton("状态 s")
        btn_status.clicked.connect(lambda: self._send("s"))
        tg.addWidget(btn_status, 1, 0, 1, 3)
        left.addWidget(tor_g)

        self._chk_watchdog = QCheckBox("软件看门狗（超限自动 d）")
        self._chk_watchdog.setChecked(True)
        left.addWidget(self._chk_watchdog)

        self._btn_estop = QPushButton("急停 STOP (d)")
        self._btn_estop.setObjectName("dangerBtn")
        self._btn_estop.clicked.connect(self._emergency_stop)
        left.addWidget(self._btn_estop)
        left.addStretch()
        body.addLayout(left, 0)
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

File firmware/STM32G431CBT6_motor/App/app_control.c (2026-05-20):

/**
 * @file    app_control.c
 * @brief   系统状态机实现
 *
 * 状态转换：
 *   INIT → CALIBRATE（外设初始化完成）
 *   CALIBRATE → READY（零偏采集完成，编码器有效）
 *   READY → RUN（app_control_enable() 被调用）
 *   RUN/READY → FAULT（软件故障检测触发）
 *   FAULT → READY（手动复位，需先清除故障源）
 *
 * 软件保护（主循环 ~1kHz 检测）：
 *   VBUS < 8V 或 > 26V → FAULT_VBUS_LOW / FAULT_VBUS_HIGH
 *   温度超限             → FAULT_TEMP
 *   编码器信号丢失       → FAULT_ENCODER
 *   任一 ADC 通道饱和    → FAULT_ADC_SATURATE
 */

#include "app_control.h"
#include "board_config.h"
#include "foc_interface.h"
#include "encoder_if.h"
#include "mpu6050.h"
#include "stm32g4xx_hal.h"
#include <string.h>
#include <math.h>   /* logf(), fmaxf(), fminf() */

/* ============================================================
 * 速度环参数（经验证稳定，平滑优先于响应速度）
 * ============================================================ */
#define KP_SPD          (0.30f)    /* A/(rad/s) - 大 KP 提供强制动 */
#define KI_SPD          (0.020f)   /* 积分克服齿槽 */
#define IQ_MAX_A        (0.25f)    /* A - 限制最大力矩防飞 */
#define IQ_SLEW_RATE_A_S (2.00f)   /* 不限制 */
#define SPEED_FF_GAIN   (0.0f)     /* 关闭前馈 */
#define SPEED_INTEG_MAX (0.20f)    /* 积分上限 */
#define OMEGA_SLEW_RATE (50.0f)    /* 不限制 */
#define FRICTION_FF_A   (0.0f)     /* 关闭 friction */
#define START_BOOST_A   (0.0f)     /* 关闭 boost */
#define START_BOOST_MS  (0U)
#define START_DONE_RPS  (0.10f)
#define STOP_DAMP_GAIN  (0.050f)
#define STOP_DAMP_MAX_A (0.15f)
#define STOP_DAMP_ON_RPS (0.20f)
#define ENC_TORQUE_HOLD_MS (25U)

/* 外部 GPIO（CubeMX 在 gpio.c 生成）*/
extern void MX_GPIO_Init(void);  /* 仅供参考，实际已由 main 调用 */

/* ============================================================
 * 内部状态
 * ============================================================ */
static AppState_t s_state = STATE_INIT;
static uint8_t    s_fault = FAULT_NONE;
static volatile float s_iq_ref_a = 0.0f;  /* q轴目标电流 [A]，主循环写、ISR 读 */

/* --- 速度环状态 --- */
static float    s_omega_est_rps  = 0.0f;   /* 滤波后速度 [rad/s] */
static float    s_omega_ref_rps  = 0.0f;   /* 经斜坡后的速度目标 [rad/s] */
static float    s_omega_ref_cmd  = 0.0f;   /* 用户目标（未经斜坡）[rad/s] */
static float    s_speed_integ    = 0.0f;   /* PI 积分项 */
static bool     s_speed_mode     = false;  /* true=速度模式, false=力矩模式 */
static uint32_t s_start_boost_until_ms = 0;
static float    s_start_boost_sign     = 0.0f;

/* --- 位置环状态 --- */
static CtrlMode_t s_ctrl_mode           = CTRL_SPEED;
static float      s_pos_home_offset_deg = 0.0f;   /* 回零时的编码器角 [deg] */
static float      s_pos_target_deg      = 0.0f;   /* 位置目标 [deg]，已clamp到±90° */
static float      s_vel_filt_dps        = 0.0f;   /* D项速度滤波 [°/s]，MOTOR_SIGN坐标系 */
static float      s_kp_pos              = 0.5f;   /* 位置P增益：半速接近目标 */
static float      s_kd_pos              = 0.15f;  /* 位置D增益：重阻尼防过冲 */
static float      s_pos_spd_lim_dps     = 45.0f;  /* 位置环输出速度限幅 [°/s]（实测稳定值）*/
static float      s_pos_deadband_deg    = 0.5f;   /* 位置死区 [deg] */
static float      s_stab_lim_deg        = 10.0f;  /* 自稳目标软限幅 [°]，默认10°，第G命令前可用 GLIM<val> 调大 */
static float      s_imu_home_offset_deg  = 0.0f;  /* IMU pitch 安装偏置，H 命令时刷新 */
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

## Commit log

2026-04-29 Initial commit: FOC controller project
    [motor_back_mount.stl, motor_shaft_clamp.stl, rotor_arm.stl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]
2026-05-12 checkpoint: FOC debug session - 7 bugs fixed, alignment identified as unstable
    Fixed:
    1. Current offset calibration (driver disabled during cal, sanity check ±300)
    2. Alignment hardcoded +1.9199f removed, PWM-off-then-read + median filter
    3. Electrical angle sign: offset-raw_e → raw_e-offset
    4. Encoder glitch filter with timeout recovery
    5. VBUS_MIN_V lowered to 4.5V
    6. SVPWM vbus from hardcoded 12V to ADC reading
    7. Encoder timeout relaxed to 200ms with glitch filter
    Remaining issue: alignment quality varies per-run causing inconsistent FOC.
    Next: refactor alignment to two-step + refactor control chain to bypass speed PI.
    [app_control.c, app_control.h, board_config.h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]
2026-05-13 milestone: current loop stabilized (f_bw=30Hz), speed mode 5/5 direction correct
    Current loop:
    - PI bandwidth reduced from 500Hz to 30Hz (Kp: 0.628→0.038, Ki: 0.424→0.025)
    - Id ripple: ±5A → ±0.4A (12x improvement)
    - Direct torque: 0.5A→164dps smooth rotation
    Speed loop:
    - FF + PI controller: FF=0.15, KP=0.02, KI=0.03, integral limit ±0.30A
    - omega_raw clamped ±10 rad/s, no IIR filter
    - 5/5 rounds direction correct, avg 6-27dps (target 30)
    Other fixes retained:
    - Current offset calibration (driver disabled during cal)
    - Alignment median filter
    - Encoder glitch filter with timeout recovery
    - Current reconstruction hysteresis
    - SVPWM vbus fixed 12V
    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
    [app_control.c, foc_interface.c]
2026-05-20 FOC gimbal stabilization: rotary ALIGN + ISR PID position control + IMU stabilize mode
    [bracket.stl, motor_back_mount.stl, motor_shaft_clamp.stl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]
2026-05-20 docs: update README with current system architecture and usage
2026-07-07 Organize repository structure
    [bracket.stl, rotor_arm.stl, 封装.pcbdoc]

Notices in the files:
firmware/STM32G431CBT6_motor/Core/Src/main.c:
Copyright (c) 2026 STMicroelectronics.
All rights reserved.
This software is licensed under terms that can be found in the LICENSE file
